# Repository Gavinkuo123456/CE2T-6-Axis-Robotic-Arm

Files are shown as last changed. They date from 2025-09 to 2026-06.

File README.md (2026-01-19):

# Cost-Effective 6 DOF robotic arm

A budget friendly 6-degree-of-freedom homemade robotic arm offering both precision and a strong load capacity for its price range.

Robot Arm CAD
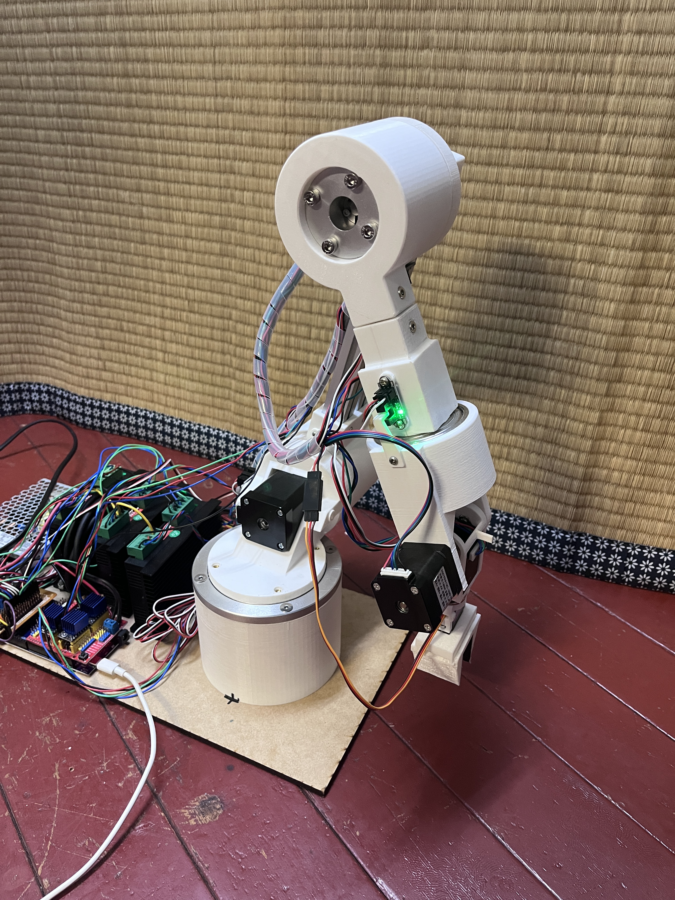
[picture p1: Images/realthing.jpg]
Robot Arm real


## 🤖 Overview

This project features a fully functional 6-DOF robotic arm that combines:
- **3D printed mechanical components** for easy production and construction
- **Stepper motor actuation** for precise positioning
- **Powerfull motor controller** for driving high-torque motors with precise control
- **Arduino-based control system** for accessibility and expandability
- **Open-loop control** for simplicity, budget-friendly and easy maintenance

## ✨ Features

- **6 Degrees of Freedom**: Full spatial movement capability
- **Stepper Motor Control**: Precise angular positioning
- **3D Printable Design**: Accessible manufacturing with standard FDM printers
- **Arduino Compatible**: Easy programming and customization
- **Open Source**: Complete design files and code available
- **standard hardware**: Easy assembly and easy to find online

## 📋 Specifications

| Parameter | Value |
|---|---|
| Degrees of Freedom | 6 |
| Motor Type | Stepper Motors |
| Control System | Arduino-based |
| Control Method | Open-loop |
| Construction | 3D Printed frame + Standard Components |
| Workspace | 500mm radius |
| Payload Capacity | ~500g |
| Repeatability | ✅ |

## 🛠️ Hardware Requirements

### Electronics
- **Arduino Board** Arduino Due
- **Stepper Motor Drivers** TMC2209 × 3 , DM542 x 3
- **Stepper Motors**
   - **Joint 1** NEMA23L56
   - **Joint 2** NEMA17L60 with 1:50 planetary gearbox
   - **Joint 3** NEMA17L48 with 1:27 planetary gearbox
   - **Joint 4** NEMA11L33 with 1:20 planetary gearbox
   - **Joint 5** NEMA14L20
   - **Joint 6** NEMA11L33
- **Power Supply** 24V 100W
- **Limit Switches** optical endstop x 6
- **Pin Header** and **General-Purpose Printed Circuit Board**(for the only custom expansion board)

### Frame
- **3D Printed Parts** (see `/3D-model` folder)

### Mechanical Components
- **Bearings** 
   - 6009 x 2
   - 6007 x1
- **Screws and Fasteners** M3, M4, M5 bolts and nuts

### Tools Required
- 3D Printer (FDM, 200×200×200mm minimum build volume)
- Screwdrivers
- Allen keys/Hex keys
- Wire strippers
- Multimeter
- Laser cutter(optional, You can use drill and hand saw)

## 🔧 Assembly Instructions

Detailed assembly instructions with images available in `/Docs/Assembly instructions.docx`

## 💻 Software Setup

### Prerequisites
- Arduino IDE (latest version)
- Required Libraries:
  - `AccelStepper`
  - `MultiStepper`
  - `math`
  - `Servo` (if using servo gripper)

## 🎮 Usage

### Basic Control
The robot arm can be controlled through:
- **Serial Commands**: Send position commands via serial monitor
- **I2C**: Send position from other device or microcontroller

### Command Examples
```
// Move to joint positions (degrees)
jm 45 30 -20 0 45 90

// Move to Cartesian position (first three in mm,last three in rad)
IK 200 150 100 0 90 0

// Home all joints
zro

// Control gripper
clm 95

```

## 📊 Kinematics

The robot arm uses standard Denavit-Hartenberg parameters for kinematic calculations. Forward and inverse kinematics algorithms are implemented for position control.

### Joint Configuration
- **Joint 1**: Base rotation (±90°)
- **Joint 2**: Shoulder pitch (±90°)
- **Joint 3**: Elbow pitch (±160°)
- **Joint 4**: Wrist roll (±180°)
- **Joint 5**: Wrist pitch (±90°)
- **Joint 6**: Wrist yaw (±180°)

## 🚀 Future Enhancements

- [ ] Closed-loop control with encoders
- [ ] Vision system integration
- [ ] ROS compatibility
- [ ] Mobile app(Browser) control
- [ ] Advanced path planning
- [ ] Machine learning integration
- [ ] Multi-arm coordination

## 🤝 Contributing

Contributions are welcome! Please feel free to submit pull requests, report bugs, or suggest improvements.

## 📝 License

This project is licensed under the MIT License - see the [LICENSE](LICENSE) file for details.

## 🙏 Acknowledgments

- Arduino community for libraries and support
- 3D printing community for design inspiration
- Robotics researchers for kinematic algorithms
- Open-source contributors

**⭐ Star this repository if you find it helpful!**

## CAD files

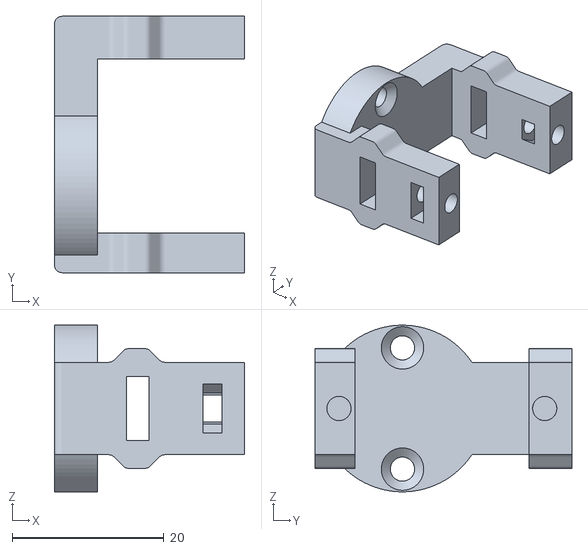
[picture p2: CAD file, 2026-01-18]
3D-model/3D print and Laser cut file/sg90 claw v2 holder.stl
25.1 x 33.8 x 22.0

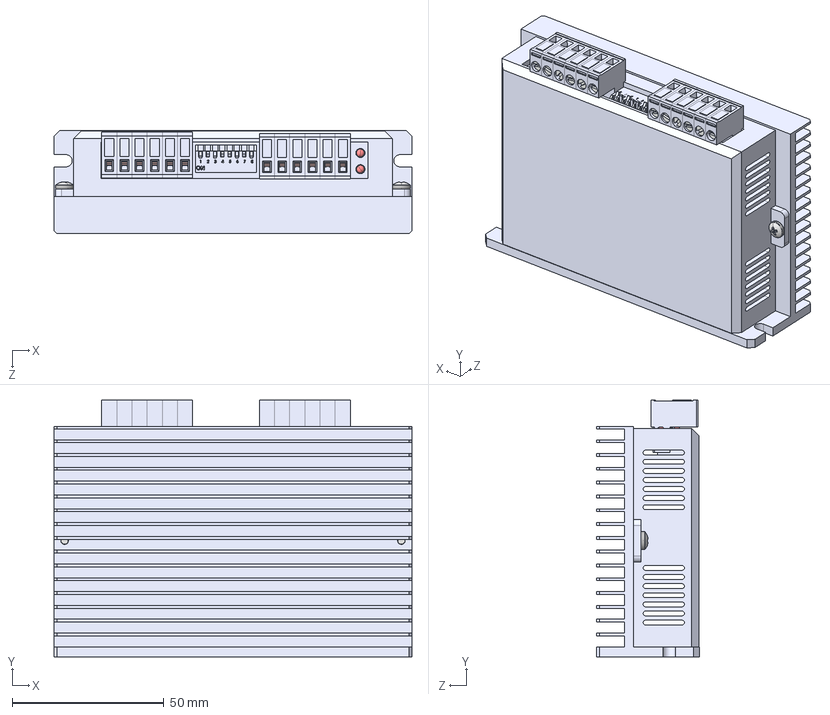
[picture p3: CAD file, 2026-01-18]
3D-model/robot armT 2(CAD file)/DM542.STEP
118.0 x 84.6 x 34.0 mm
散熱片
外殼
Pan Head M3x5_96741A118 x 2
端子(1P) x 12
ｩTｩwﾁｳｵｷ x 12
緊迫 x 12
LED x 2
DIP Switch
Switch x 8

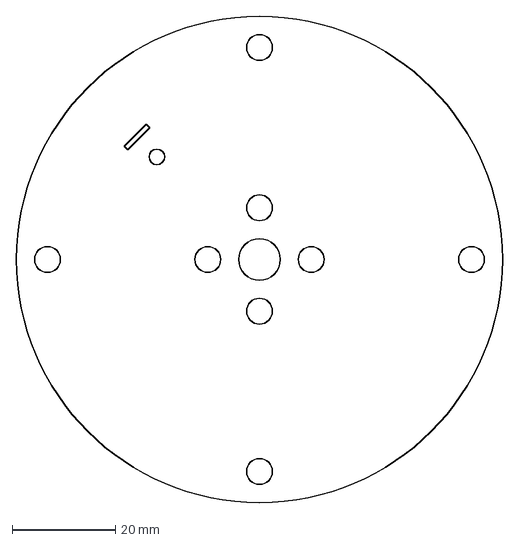
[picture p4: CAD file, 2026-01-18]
3D-model/3D print and Laser cut file/j1 moving plate laser cut.dxf
94.0 x 94.0 mm

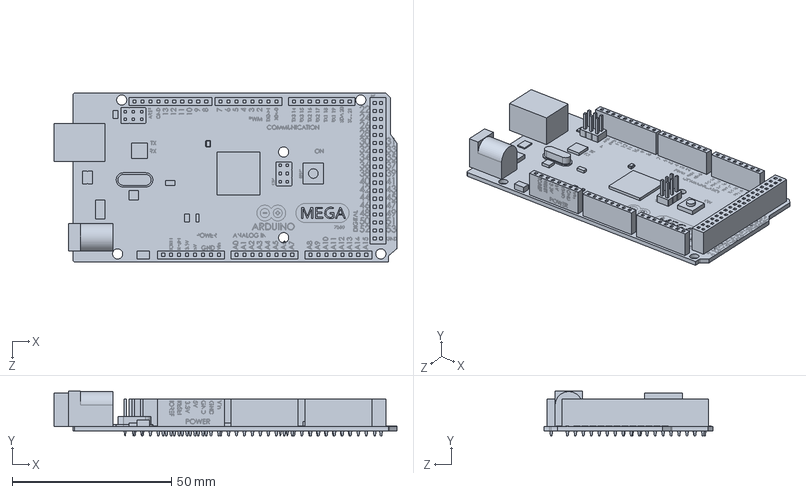
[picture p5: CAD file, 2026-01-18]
3D-model/robot armT 2(CAD file)/ArduinoMega2560.SLDPRT
107.6 x 14.0 x 53.0 mm

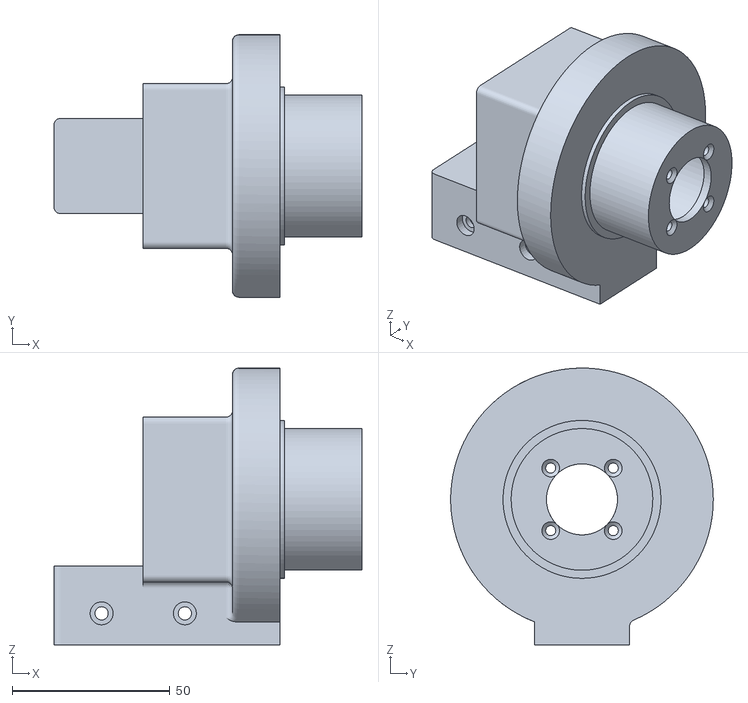
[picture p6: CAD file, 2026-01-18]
3D-model/3D print and Laser cut file/j3 motor mount.stl
97.5 x 83.1 x 87.6

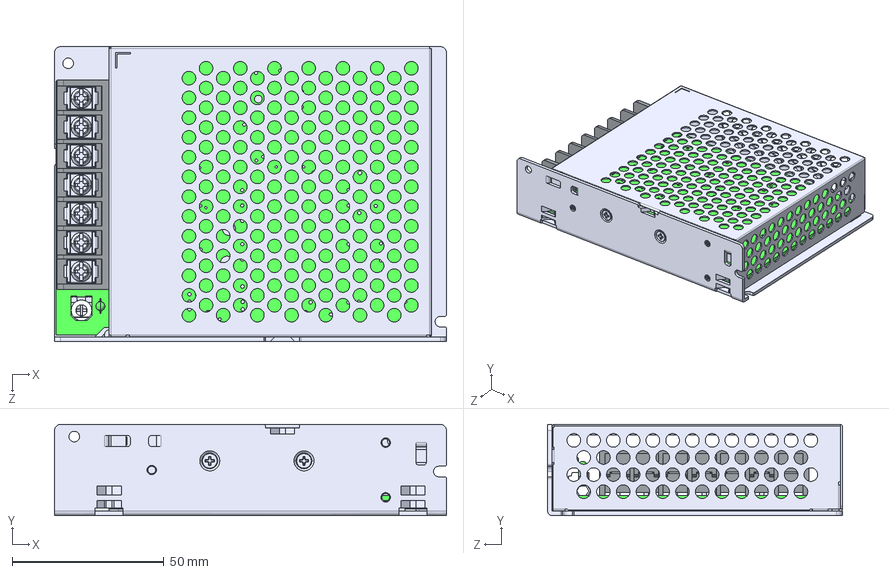
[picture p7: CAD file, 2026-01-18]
3D-model/robot armT 2(CAD file)/VTX-212-100-0xx.STEP
129.0 x 30.0 x 97.0 mm
CHASSIS_40
LUOZHU_2
COVER_29
PRT0028_2
PRT0052_2 x 2
PRT0053_3 x 2
PRT0054_AF0_2
PRT0054_AF1_2
PRT0054_AF2_2
PRT0054_AF3_2
PRT0054_AF4_2
PRT0054_AF5_2
PRT0054_AF6_2
PRT0054_AF7_2
PRT0054_AF8_2
PRT0054_AF9_2
PRT0054_AF10_2
PRT0054_AF11_2
PRT0054_AF12_2
PRT0054_AF13_2
PRT0054_AF14_2
PRT0054_AF15_2
PRT0055_2 x 32
PRT0056_2 x 32
PRT0061_AF0_2
KM3X10_3 x 2
KM3X5_2
PRT0054_2 x 16
PRT0061_2

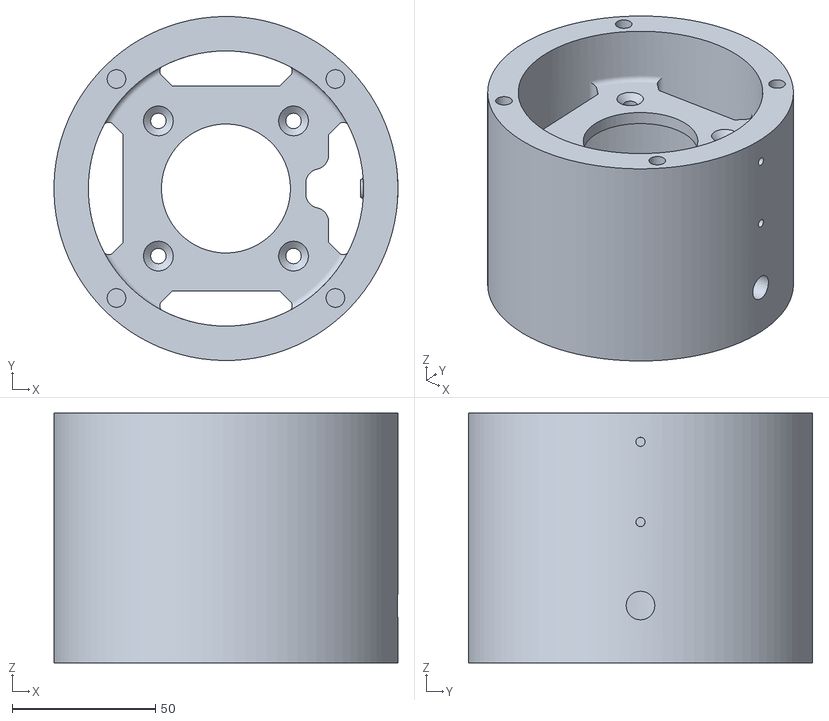
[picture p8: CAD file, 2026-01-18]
3D-model/3D print and Laser cut file/j1 57 mount.stl
120.0 x 120.0 x 87.1

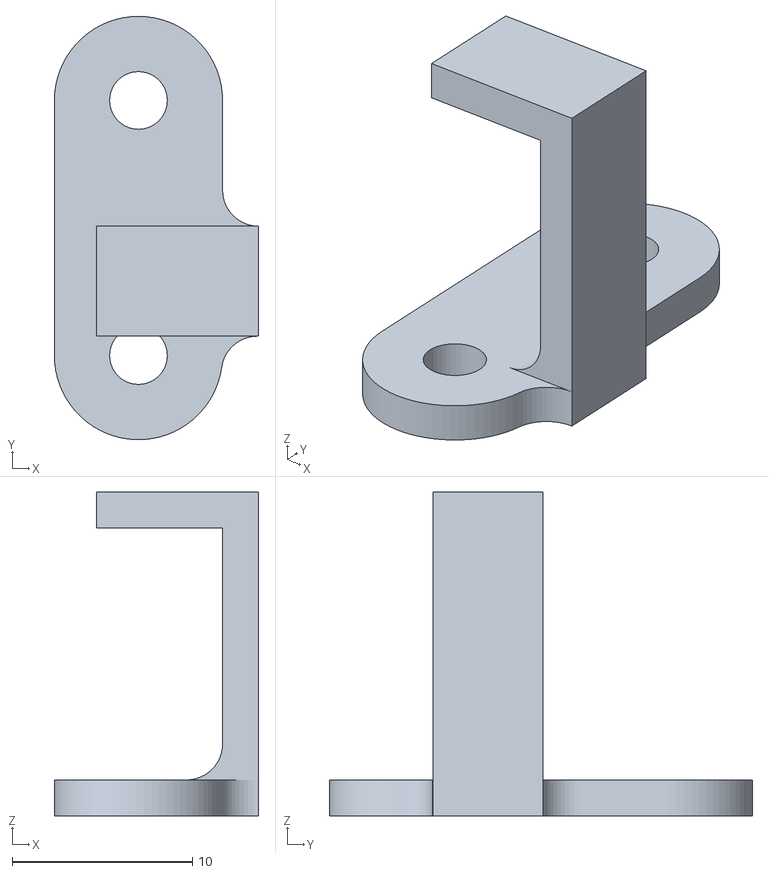
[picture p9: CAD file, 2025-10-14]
3D-model/3D print and Laser cut file/j2 endstop blocker.stl
11.3 x 23.5 x 18.0

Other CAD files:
3D-model/robot armT 2(CAD file)/AS 1427 - M3 x 6(5) II.ipt
3D-model/robot armT 2(CAD file)/AS 1474 - M3(1).ipt
3D-model/robot armT 2(CAD file)/AS 1474 - M4(1).ipt
3D-model/robot armT 2(CAD file)/ArduinoMega2560/ArduinoMega2560/ArduinoMega2560.ipt
3D-model/robot armT 2(CAD file)/CNS 2862 B2116 - 6007 - 35 x 62 x 14.ipt
3D-model/robot armT 2(CAD file)/CNS 4557 - M4 x 0.7 x 10.ipt
3D-model/robot armT 2(CAD file)/CNS 4558 - M3 x 0.5 x 10.ipt
3D-model/robot armT 2(CAD file)/DM542/DM542/DM542.ipt
3D-model/robot armT 2(CAD file)/M3 heat set insert.ipt
3D-model/robot armT 2(CAD file)/M3 heat set inserts.ipt
3D-model/robot armT 2(CAD file)/M5 heat set inserts.ipt
3D-model/robot armT 2(CAD file)/OldVersions/CNS 2862 B2116 - 6007 - 35 x 62 x 14.0001.ipt
3D-model/robot armT 2(CAD file)/OldVersions/base plate.0005.ipt
3D-model/robot armT 2(CAD file)/OldVersions/j1 57 mount.0015.ipt
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

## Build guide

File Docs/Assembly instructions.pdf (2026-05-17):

## Laser cut Plate preparation

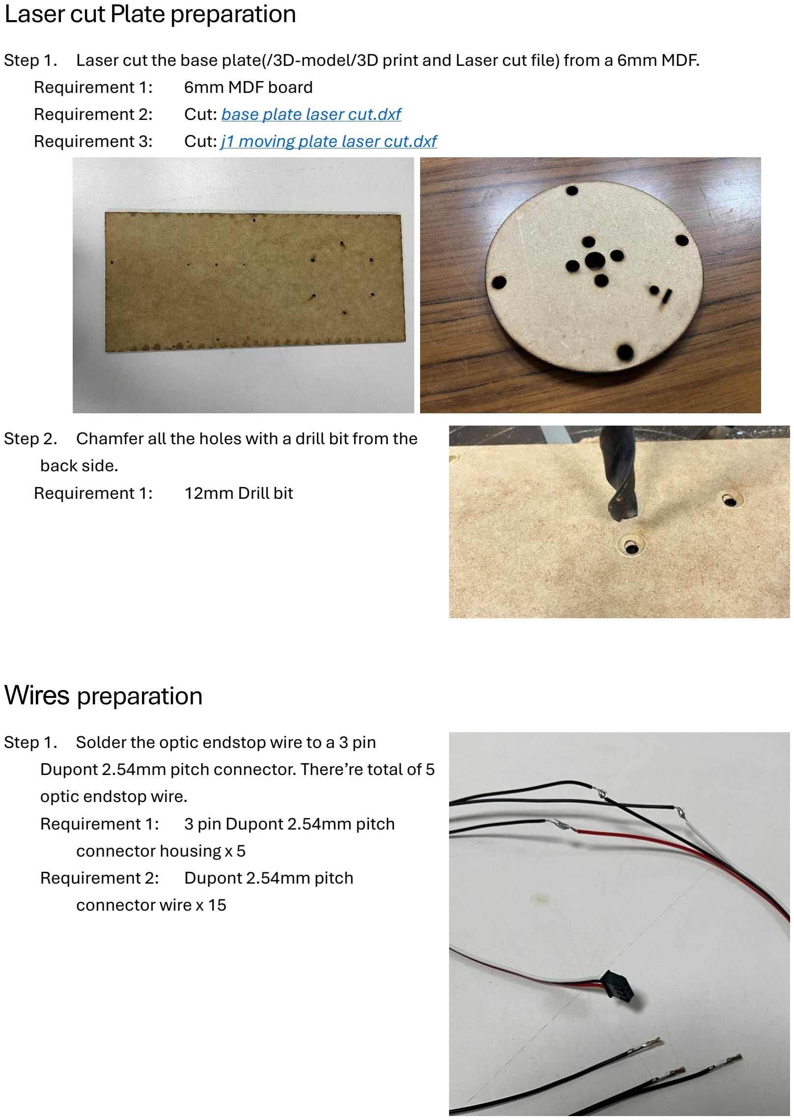
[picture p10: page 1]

Step 1. Laser cut the base plate(/3D-model/3D print and Laser cut file) from a 6mm MDF.
Requirement 1: | 6mm MDF board
Requirement 2: | Cut: base plate laser cut.dxf (https://github.com/Gavinkuo123456/CE2T-6-Axis-Robotic-Arm/blob/main/3D-model/3D%20print%20and%20Laser%20cut%20file/base%20plate%20laser%20cut.dxf)
Requirement 3: | Cut: j1 moving plate laser cut.dxf (https://github.com/Gavinkuo123456/CE2T-6-Axis-Robotic-Arm/blob/main/3D-model/3D%20print%20and%20Laser%20cut%20file/j1%20moving%20plate%20laser%20cut.dxf)
Step 2. Chamfer all the holes with a drill bit from the back side.
Requirement 1: 12mm Drill bit

## Wires preparation

Step 1. Solder the optic endstop wire to a 3 pin Dupont 2.54mm pitch connector. There’re total of 5 optic endstop wire.
Requirement 1: 3 pin Dupont 2.54mm pitch connector housing x 5
Requirement 2: Dupont 2.54mm pitch connector wire x 15

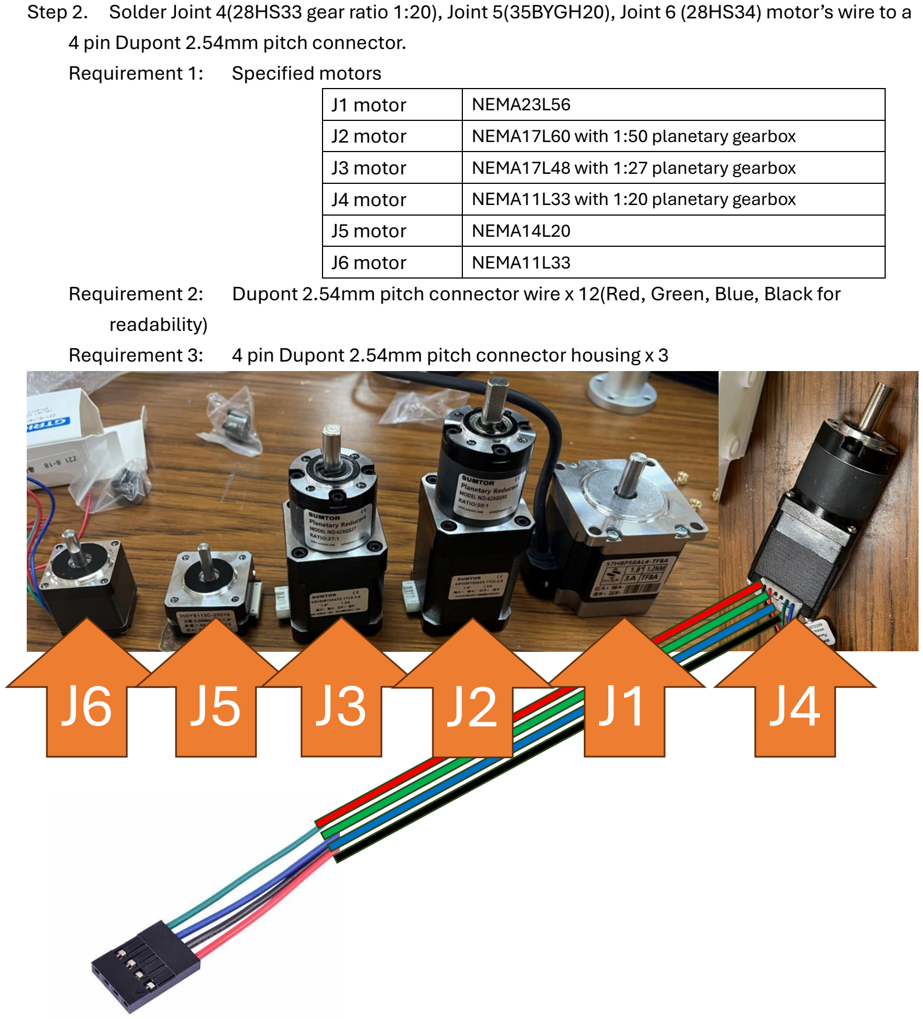
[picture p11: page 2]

Step 2. Solder Joint 4(28HS33 gear ratio 1:20), Joint 5(35BYGH20), Joint 6 (28HS34) motor’s wire to a 4 pin Dupont 2.54mm pitch connector.
Requirement 1: Specified motors
J1 motor | NEMA23L56
J2 motor | NEMA17L60 with 1:50 planetary gearbox
J3 motor | NEMA17L48 with 1:27 planetary gearbox
J4 motor | NEMA11L33 with 1:20 planetary gearbox
J5 motor | NEMA14L20
J6 motor | NEMA11L33
Requirement 2: Dupont 2.54mm pitch connector wire x 12(Red, Green, Blue, Black for readability)
Requirement 3: 4 pin Dupont 2.54mm pitch connector housing x 3
J6 J5 J3 J2 | J1 | J4

## Joint 1 assembly

3D printed parts
1. j1 57 mount.stl (https://github.com/Gavinkuo123456/CE2T-6-Axis-Robotic-Arm/blob/main/3D-model/3D%20print%20and%20Laser%20cut%20file/j1%2057%20mount.stl)
2. j1 endstop block v2.stl (https://github.com/Gavinkuo123456/CE2T-6-Axis-Robotic-Arm/blob/main/3D-model/3D%20print%20and%20Laser%20cut%20file/j1%20endstop%20block%20v2.stl)
Step 1. Tap M5 threads into 8mm flange coupling Requirement 1: 8mm flange coupling Requirement 2: M5 Taps

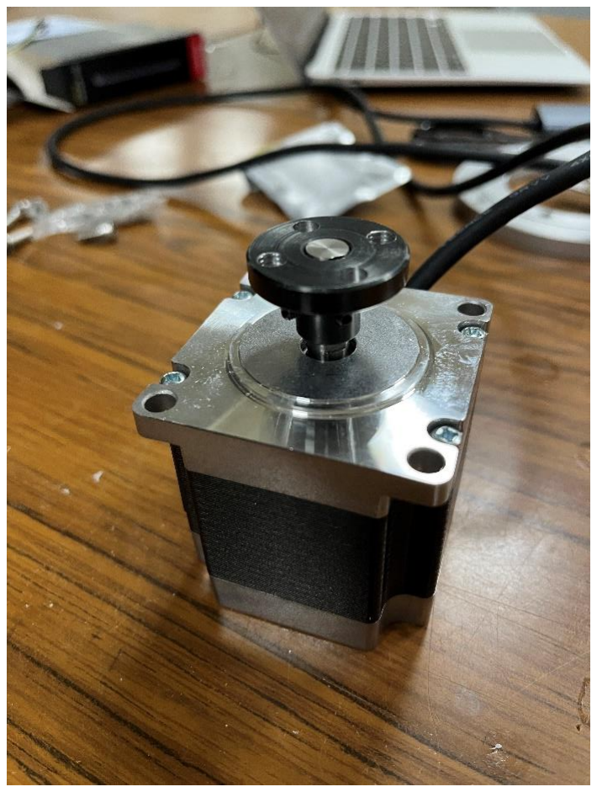
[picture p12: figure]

Step 2. Install the Coupling on to the shaft of the NEMA 23 motor.
Requirement 1: NEMA23 x 56mm Requirement 2: Tapped 8mm coupling

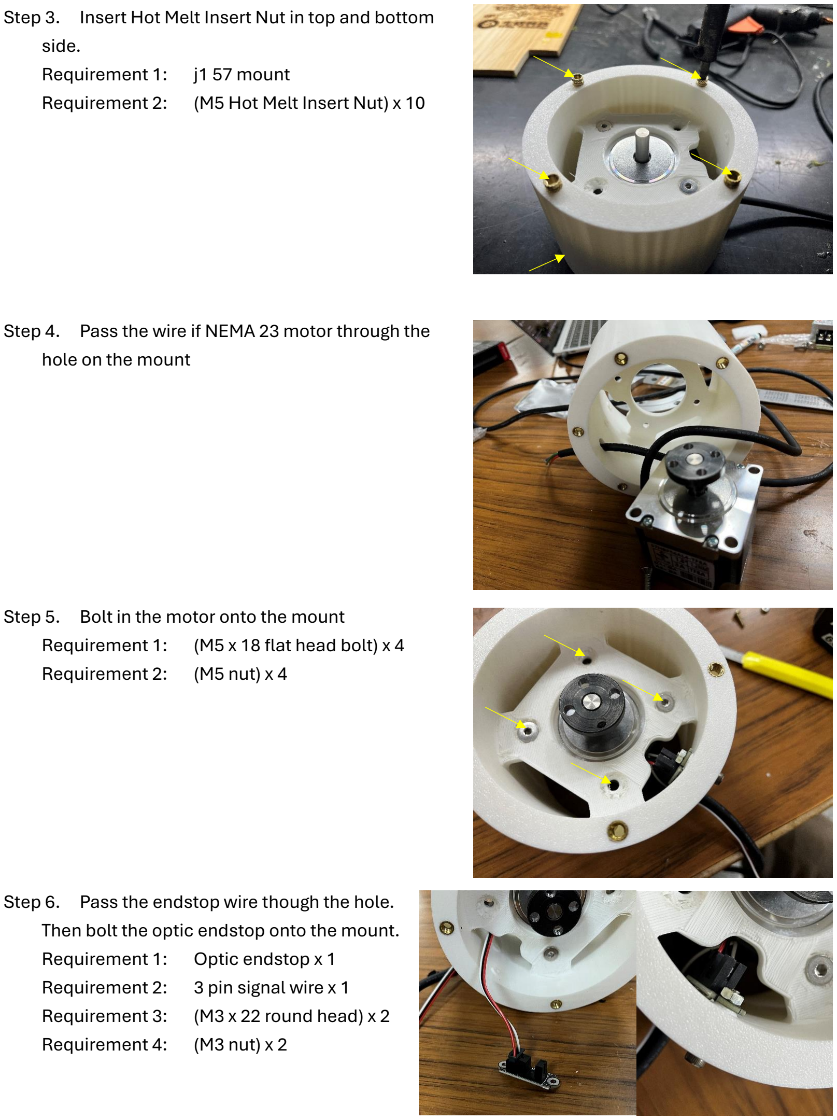
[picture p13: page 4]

Step 3. Insert Hot Melt Insert Nut in top and bottom side.
Requirement 1: j1 57 mount
Requirement 2: (M5 Hot Melt Insert Nut) x 10
Step 4. Pass the wire if NEMA 23 motor through the hole on the mount
Step 5. Bolt in the motor onto the mount Requirement 1: (M5 x 18 flat head bolt) x 4 Requirement 2: (M5 nut) x 4
Step 6. Pass the endstop wire though the hole. Then bolt the optic endstop onto the mount. Requirement 1: Optic endstop x 1 Requirement 2: 3 pin signal wire x 1 Requirement 3: (M3 x 22 round head) x 2 Requirement 4: (M3 nut) x 2

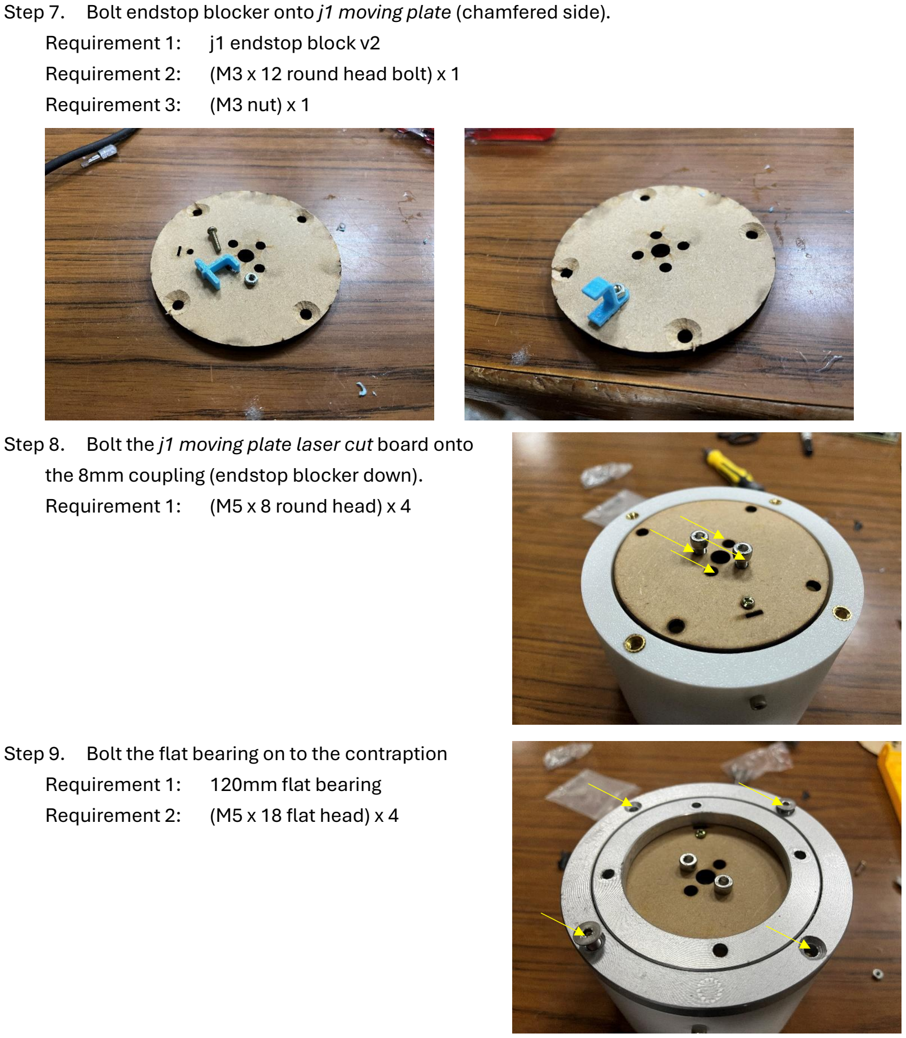
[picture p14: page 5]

Step 7. Bolt endstop blocker onto j1 moving plate (chamfered side). Requirement 1: j1 endstop block v2
Requirement 2: (M3 x 12 round head bolt) x 1
Requirement 3: (M3 nut) x 1
Step 8. Bolt the j1 moving plate laser cut board onto the 8mm coupling (endstop blocker down). Requirement 1: (M5 x 8 round head) x 4
Step 9. Bolt the flat bearing on to the contraption Requirement 1: 120mm flat bearing Requirement 2: (M5 x 18 flat head) x 4

Joint 2 assembly

Step 1. prepare the necessary parts

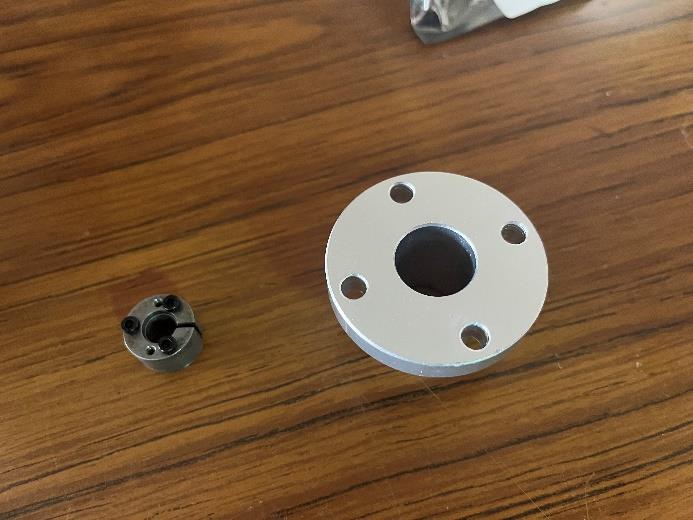
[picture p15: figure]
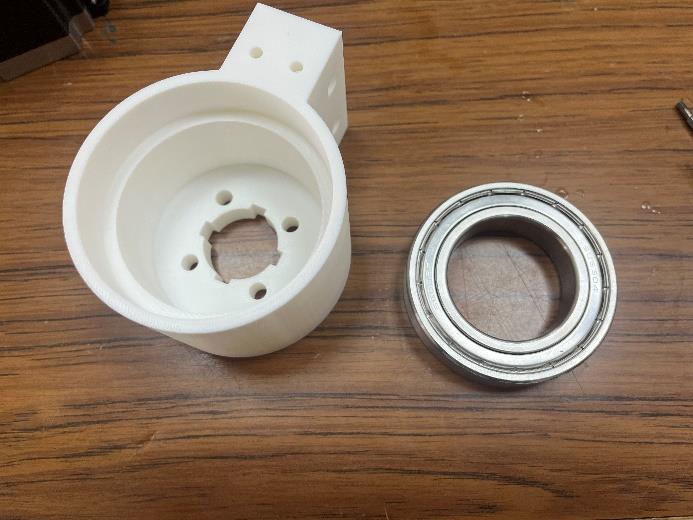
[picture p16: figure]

Step 2. Install Insert Nut on j2 42 motor mount.stl (https://github.com/Gavinkuo123456/CE2T-6-Axis-Robotic-Arm/blob/main/3D-model/3D%20print%20and%20Laser%20cut%20file/j2%2042%20motor%20mount.stl) and j2 moving part option2.stl (https://github.com/Gavinkuo123456/CE2T-6-Axis-Robotic-Arm/blob/main/3D-model/3D%20print%20and%20Laser%20cut%20file/j2%20moving%20part%20option2.stl)
Requirement 1: | (heat M5 Hot Melt Insert Nut) x 8
Requirement 2: | (heat M3 Hot Melt Insert Nut) x 4

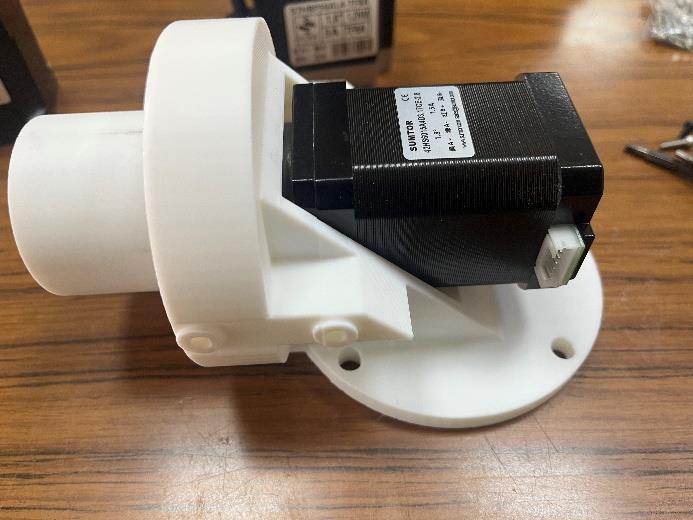
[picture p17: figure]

Step 3. Install J2 motor in to the mount, use 4 screws to hold it in place
Requirement 1: | J2 motor
Requirement 2: | (M3 x 6 flathead) x 4
Step 4. Assemble axle locking assembly, tighten the allen screws by the side of the flange Requirement 1: Expansion Bushing (Z21-ID 8 * OD 18)
Requirement 2: Flange (ID18)

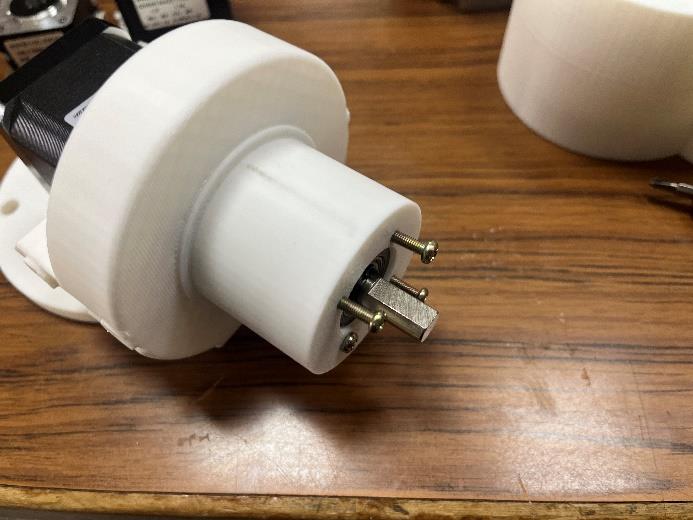
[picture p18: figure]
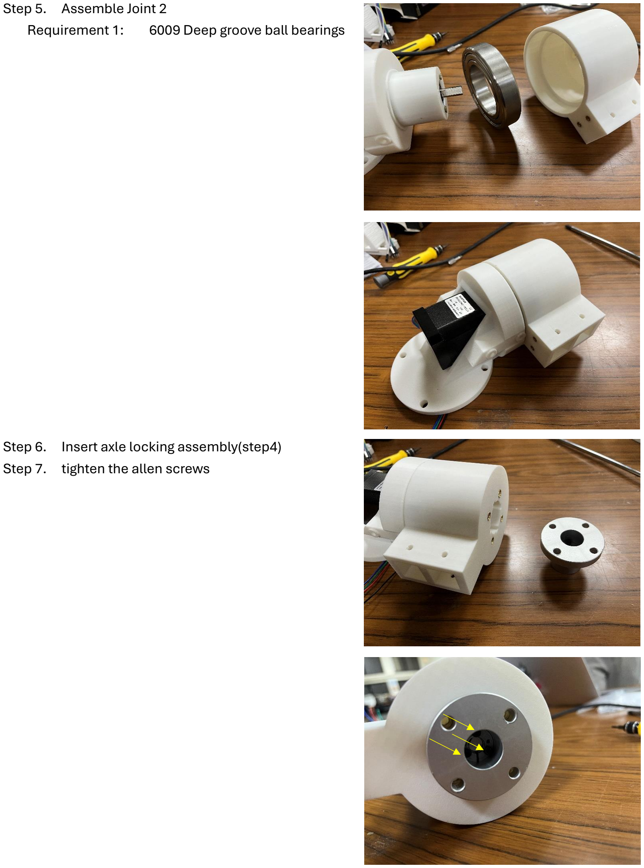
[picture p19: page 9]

Step 5. Assemble Joint 2
Requirement 1: 6009 Deep groove ball bearings
Step 6. Insert axle locking assembly(step4)
Step 7. tighten the allen screws

Step 8. Fasten connecting bolts Requirement 1: (M5 x 16) x 4

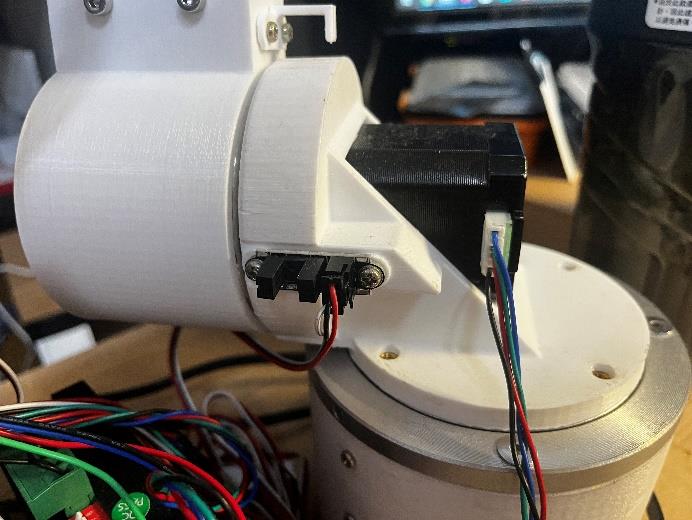
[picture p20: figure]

Step 9. Install endstop, make sure it is facing the right direction
Requirement 1: | Optical endstop
Requirement 2: | (M3x6) x 2
Step 10. Install endstop blocker
Requirement 1: | j2 endstop blocker.stl (https://github.com/Gavinkuo123456/CE2T-6-Axis-Robotic-Arm/blob/main/3D-model/3D%20print%20and%20Laser%20cut%20file/j2%20endstop%20blocker.stl)
Requirement 2: | (M3x6) x 2

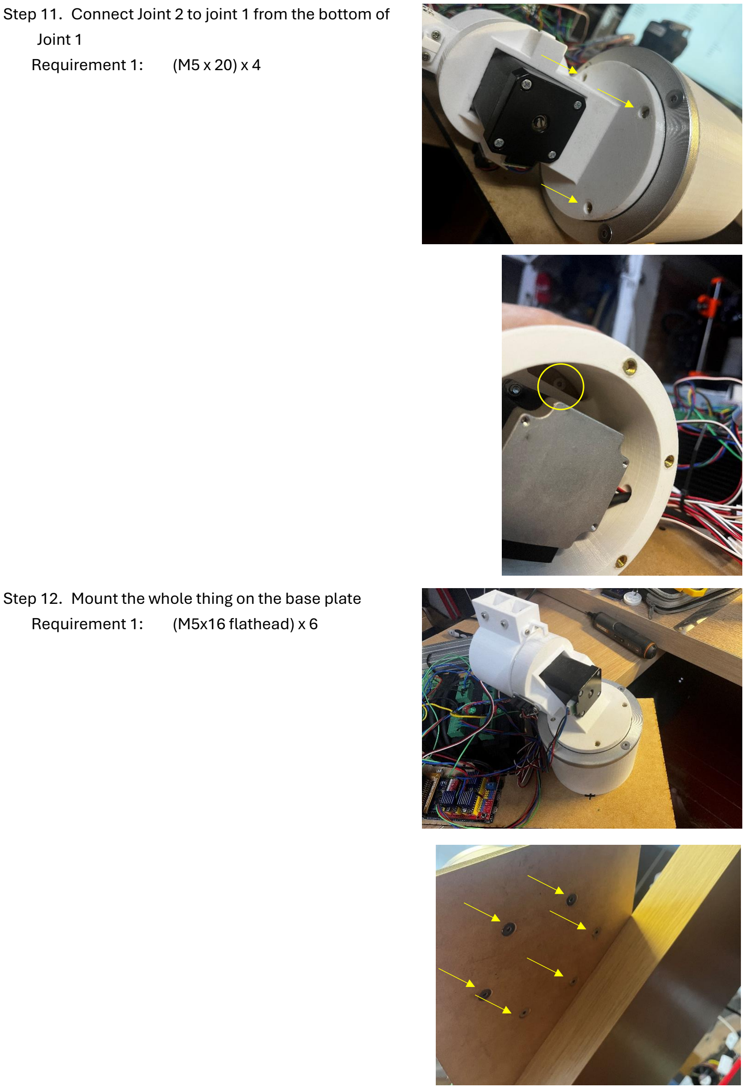
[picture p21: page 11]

Step 11. Connect Joint 2 to joint 1 from the bottom of Joint 1
Requirement 1: (M5 x 20) x 4
Step 12. Mount the whole thing on the base plate Requirement 1: (M5x16 flathead) x 6

Joint 3 assembly

Step 1. Prepare the necessary parts

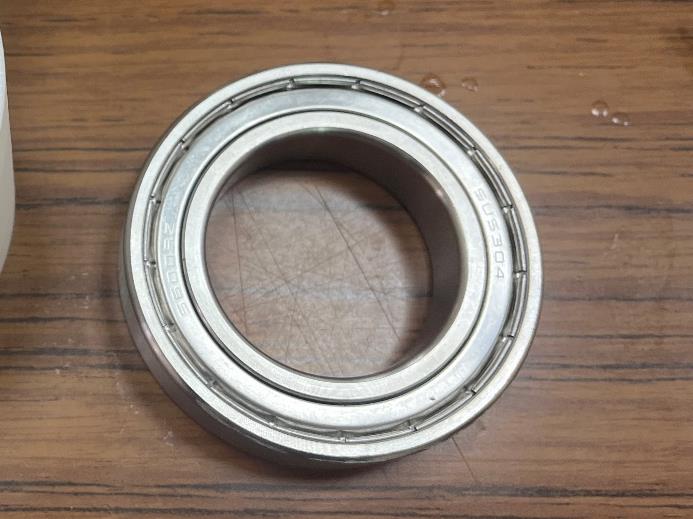
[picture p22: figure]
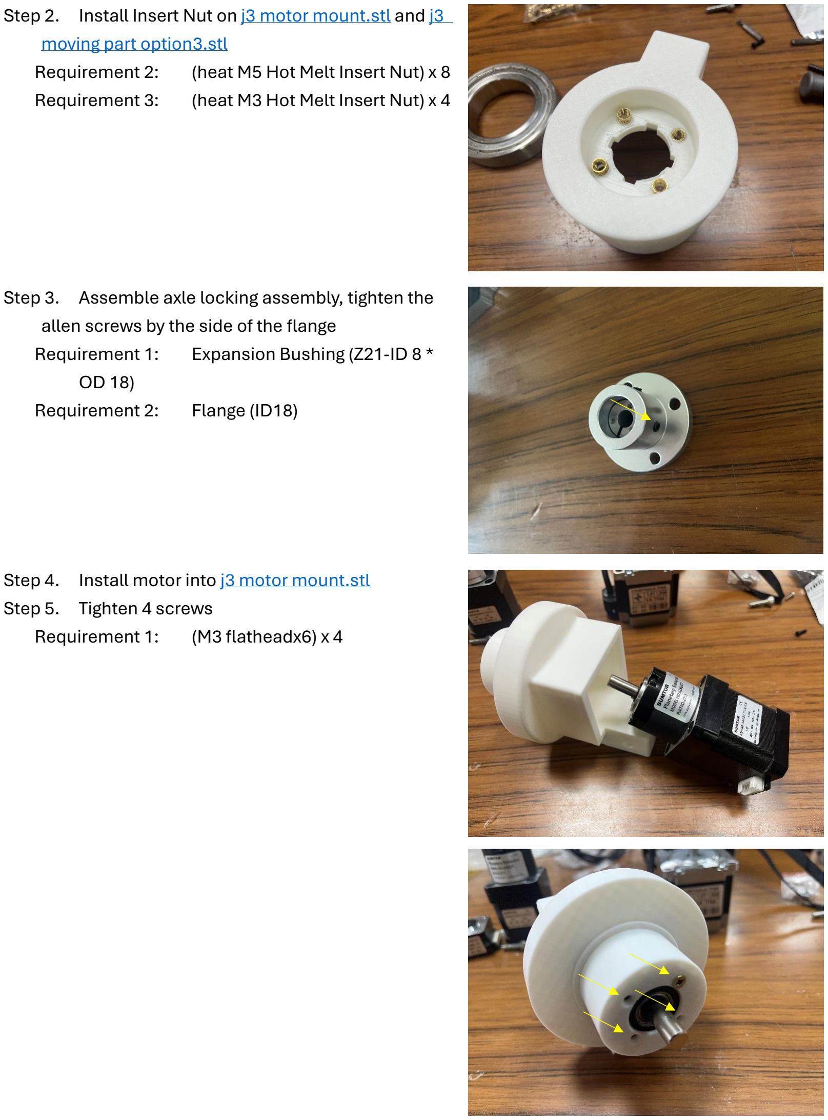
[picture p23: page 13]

Step 2. Install Insert Nut on j3 motor mount.stl (https://github.com/Gavinkuo123456/CE2T-6-Axis-Robotic-Arm/blob/main/3D-model/3D%20print%20and%20Laser%20cut%20file/j3%20motor%20mount.stl) and j3 moving part option3.stl (https://github.com/Gavinkuo123456/CE2T-6-Axis-Robotic-Arm/blob/main/3D-model/3D%20print%20and%20Laser%20cut%20file/j3%20moving%20part%20option3.stl)
Requirement 2: | (heat M5 Hot Melt Insert Nut) x 8
Requirement 3: | (heat M3 Hot Melt Insert Nut) x 4
Step 3. Assemble axle locking assembly, tighten the allen screws by the side of the flange Requirement 1: Expansion Bushing (Z21-ID 8 * OD 18)
Requirement 2: Flange (ID18)
Step 4. Install motor into j3 motor mount.stl (https://github.com/Gavinkuo123456/CE2T-6-Axis-Robotic-Arm/blob/main/3D-model/3D%20print%20and%20Laser%20cut%20file/j3%20motor%20mount.stl)
Step 5. Tighten 4 screws
Requirement 1: (M3 flatheadx6) x 4

Step 6. Install axle locking assembly into j3 moving part option3(step 2) and tighten 4 bolts Requirement 1: (M5 x 16) x 4

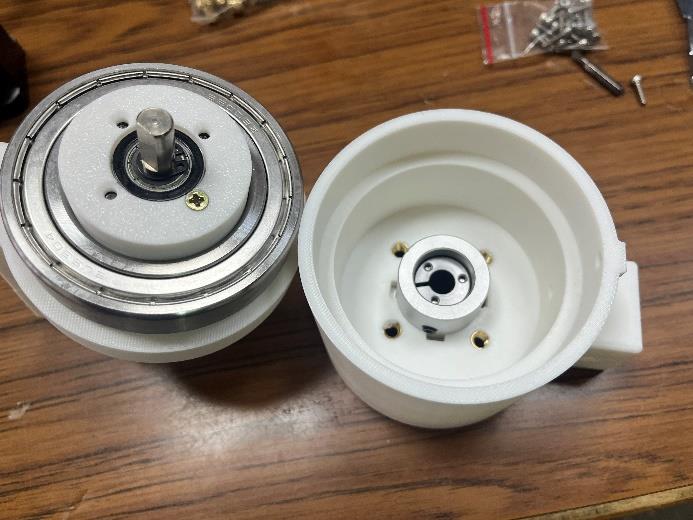
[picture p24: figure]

Step 7. Assemble joint 3

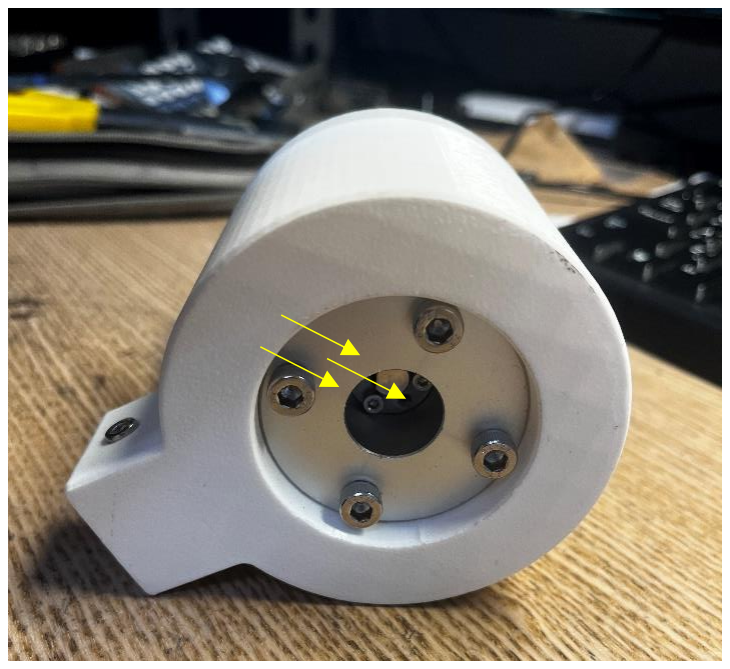
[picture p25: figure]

Step 8. Tighten the allen screws

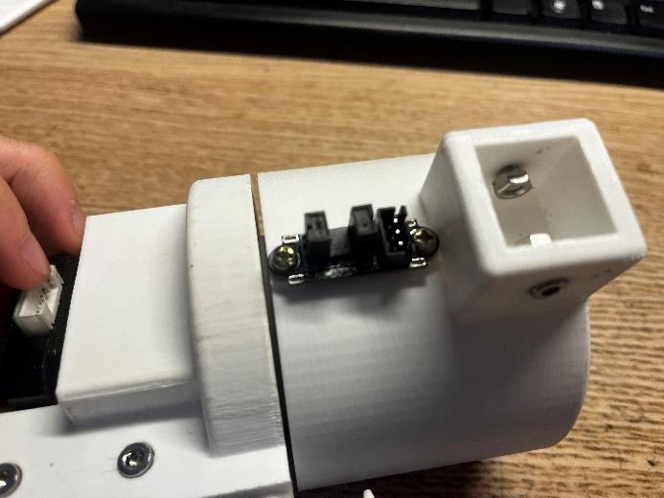
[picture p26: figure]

Step 9. Install endstop, make sure it is facing the right direction
Requirement 1: | Optical endstop
Requirement 2: | (M3x6) x 2
Step 10. Install endstop blocker
Requirement 1: | j3 endstop blocker.stl (https://github.com/Gavinkuo123456/CE2T-6-Axis-Robotic-Arm/blob/main/3D-model/3D%20print%20and%20Laser%20cut%20file/j3%20endstop%20blocker.stl)
Requirement 2: | (M3x6) x 2

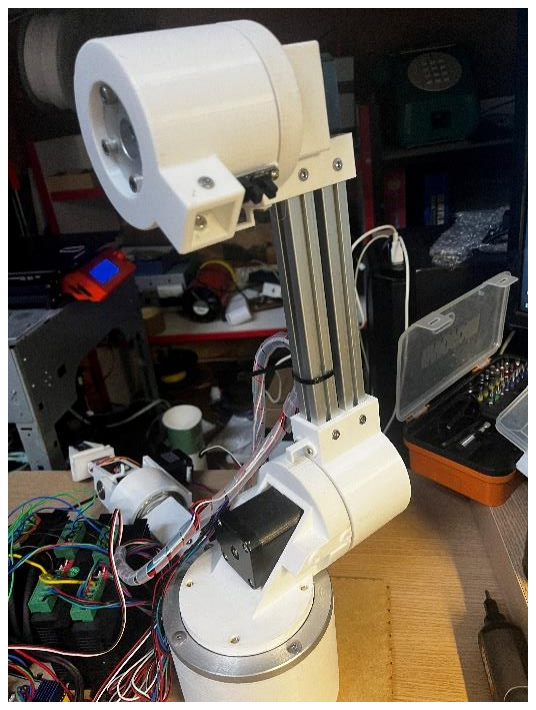
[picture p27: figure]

Step 11. Connect Joint 3 to the base part, blot down the whole thing with M4 bolts and buts
Requirement 1: | 2020aluminum extrusion 180mm
Requirement 2: | (M4x8) x 8
Requirement 3: | M4 nuts x 8
Step 12. 50% of the arm is complete

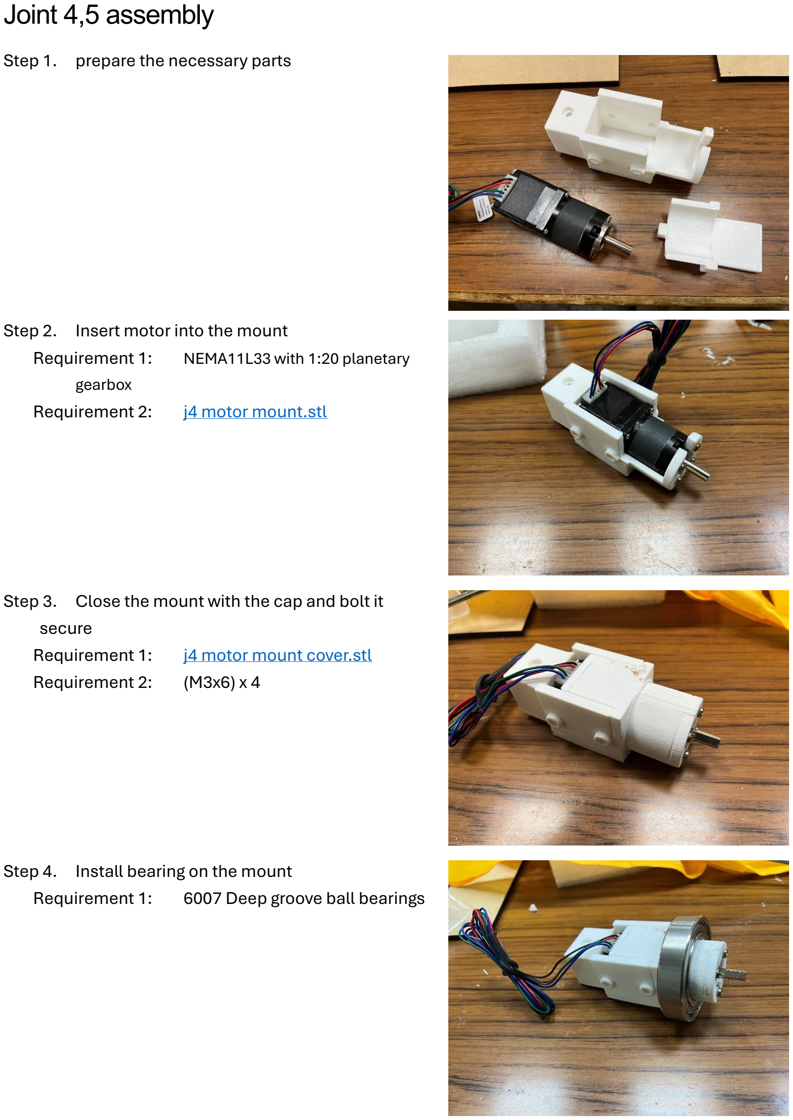
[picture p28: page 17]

Joint 4,5 assembly

Step 1. prepare the necessary parts
Step 2. Insert motor into the mount
Requirement 1: NEMA11L33 with 1:20 planetary gearbox
Requirement 2: j4 motor mount.stl (https://github.com/Gavinkuo123456/CE2T-6-Axis-Robotic-Arm/blob/main/3D-model/3D%20print%20and%20Laser%20cut%20file/j4%20motor%20mount.stl)
Step 3. Close the mount with the cap and bolt it secure
Requirement 1: | j4 motor mount cover.stl (https://github.com/Gavinkuo123456/CE2T-6-Axis-Robotic-Arm/blob/main/3D-model/3D%20print%20and%20Laser%20cut%20file/j4%20motor%20mount%20cover.stl)
Requirement 2: | (M3x6) x 4
Step 4. Install bearing on the mount
Requirement 1: 6007 Deep groove ball bearings

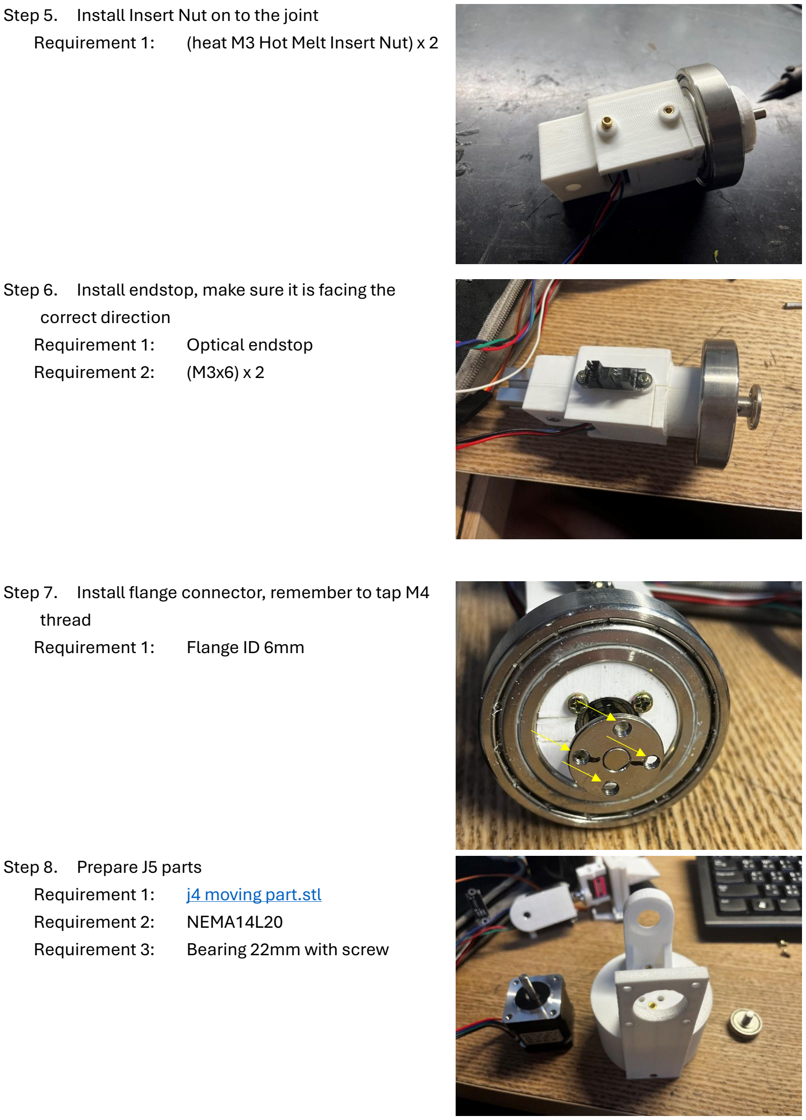
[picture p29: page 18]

Step 5. Install Insert Nut on to the joint
Requirement 1: (heat M3 Hot Melt Insert Nut) x 2
Step 6. Install endstop, make sure it is facing the correct direction
Requirement 1: | Optical endstop
Requirement 2: | (M3x6) x 2
Step 7. Install flange connector, remember to tap M4 thread
Requirement 1: Flange ID 6mm
Step 8. Prepare J5 parts
Requirement 1: | j4 moving part.stl (https://github.com/Gavinkuo123456/CE2T-6-Axis-Robotic-Arm/blob/main/3D-model/3D%20print%20and%20Laser%20cut%20file/j4%20moving%20part.stl)
Requirement 2: | NEMA14L20
Requirement 3: | Bearing 22mm with screw

Step 9. Install Insert Nut
Requirement 1: (heat M3 Hot Melt Insert Nut) x 3
Step 10. Assemble joint 4 and joint 5
Step 11. Bolt down joint 5 to joint 4 motor Requirement 1: (M5x10) x 4

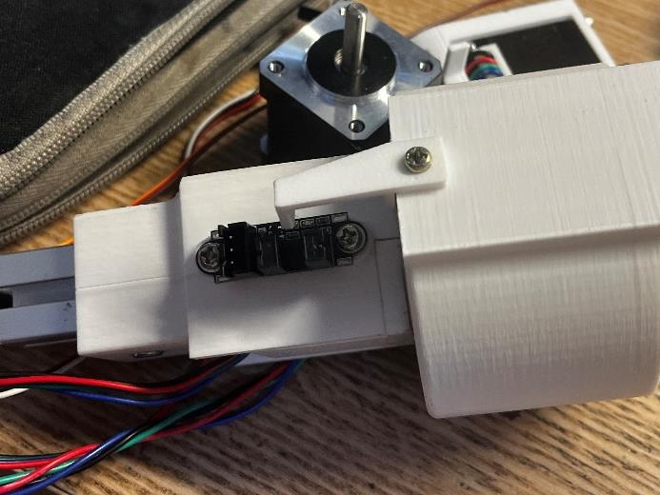
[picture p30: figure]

Step 12. Install endstop blocker
Requirement 1: | j4 endstop blocker.stl (https://github.com/Gavinkuo123456/CE2T-6-Axis-Robotic-Arm/blob/main/3D-model/3D%20print%20and%20Laser%20cut%20file/j4%20endstop%20blocker.stl)
Requirement 2: | M3x6

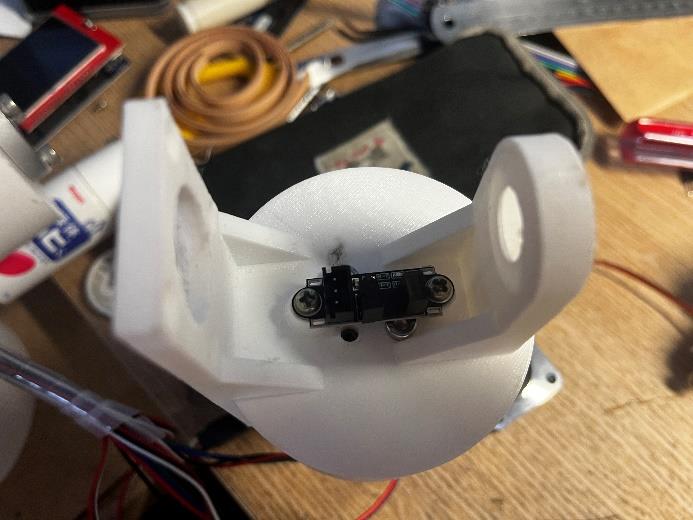
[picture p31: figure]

Step 13. Install endstop
Requirement 1: | Optical endstop
Requirement 2: | (M3x6) x 2

We need to jump to Joint 6 assembly for now Joint 6 assembly

Step 1. Prepare the parts

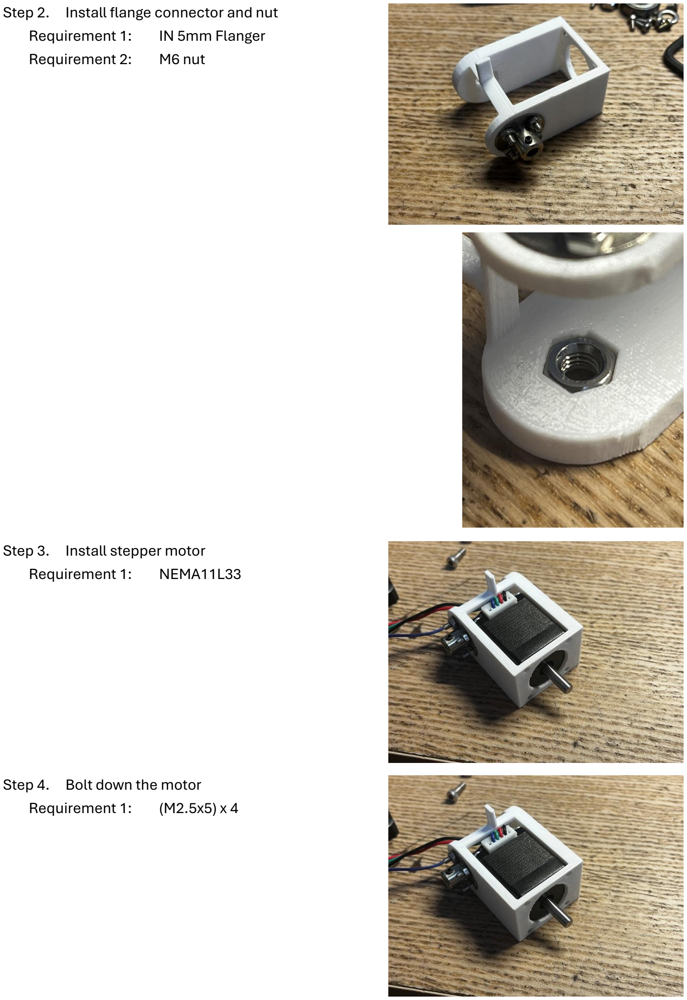
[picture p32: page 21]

Step 2. Install flange connector and nut
Requirement 1: | IN 5mm Flanger
Requirement 2: | M6 nut
Step 3. Install stepper motor Requirement 1: NEMA11L33
Step 4. Bolt down the motor Requirement 1: (M2.5x5) x 4

Step 5.
Step 6. Connect joint 6 to Joint 4,5 part(bearing side)
Step 14. Connect Joint 6 to Joint 5 motor axle and bolt down the allen screw
Step 15. Bolt down joint 5 motor Requirement 1: (M3flatheadx5) x 4

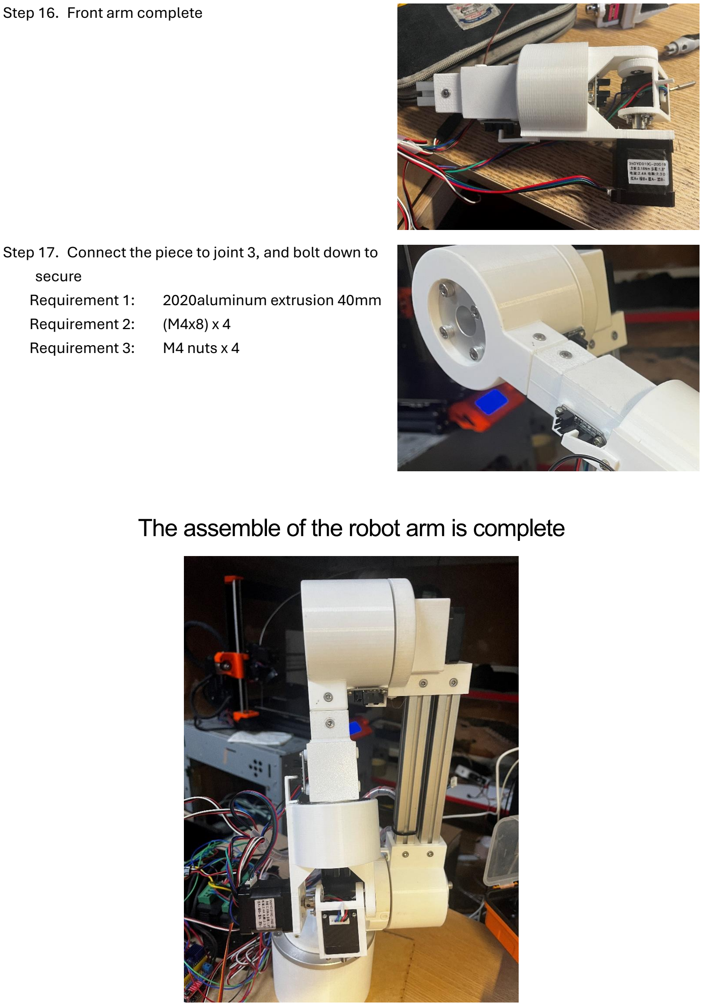
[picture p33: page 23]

Step 16. Front arm complete
Step 17. Connect the piece to joint 3, and bolt down to secure
Requirement 1: | 2020aluminum extrusion 40mm
Requirement 2: | (M4x8) x 4
Requirement 3: | M4 nuts x 4

The assemble of the robot arm is complete

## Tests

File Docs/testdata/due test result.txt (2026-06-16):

[10:34:37.543] [TX ] IK 150 0 150 0 3.14 0
[10:34:38.549] [RX ] Received IK event
[10:34:38.582] [RX ] -0.000081 -0.145631 2.236321 -0.002232 1.049270 0.000976
[10:34:38.582] [RX ] A motor move = -0.00
[10:34:38.586] [RX ] B motor move = -8.34
[10:34:38.586] [RX ] C motor move = 128.13
[10:34:38.590] [RX ] D motor move = -0.13
[10:34:38.590] [RX ] E motor move = 60.12
[10:34:38.593] [RX ] F motor move = 0.06
[10:35:13.951] [TX ] IK 150 0 200 0 3.14 0
[10:35:14.957] [RX ] Received IK event
[10:35:15.006] [RX ] -0.000110 -0.233804 2.051406 -0.001634 1.322403 0.000260
[10:35:15.006] [RX ] A motor move = -0.01
[10:35:15.006] [RX ] B motor move = -13.40
[10:35:15.007] [RX ] C motor move = 117.54
[10:35:15.007] [RX ] D motor move = -0.09
[10:35:15.007] [RX ] E motor move = 75.77
[10:35:15.007] [RX ] F motor move = 0.01
[10:35:19.655] [TX ] IK 150 0 150 0 3.14 0
[10:35:20.662] [RX ] Received IK event
[10:35:20.691] [RX ] -0.000081 -0.145631 2.236321 -0.002232 1.049270 0.000976
[10:35:20.695] [RX ] A motor move = -0.00
[10:35:20.695] [RX ] B motor move = -8.34
[10:35:20.699] [RX ] C motor move = 128.13
[10:35:20.699] [RX ] D motor move = -0.13
[10:35:20.703] [RX ] E motor move = 60.12
[10:35:20.703] [RX ] F motor move = 0.06
[10:35:24.231] [TX ] IK 150 0 200 0 3.14 0
[10:35:25.237] [RX ] Received IK event
[10:35:25.274] [RX ] -0.000110 -0.233804 2.051406 -0.001634 1.322403 0.000260
[10:35:25.275] [RX ] A motor move = -0.01
[10:35:25.275] [RX ] B motor move = -13.40
[10:35:25.278] [RX ] C motor move = 117.54
[10:35:25.279] [RX ] D motor move = -0.09
[10:35:25.282] [RX ] E motor move = 75.77
[10:35:25.283] [RX ] F motor move = 0.01
[10:35:28.807] [TX ] IK 150 0 150 0 3.14 0
[10:35:29.812] [RX ] Received IK event
[10:35:29.845] [RX ] -0.000081 -0.145631 2.236321 -0.002232 1.049270 0.000976
[10:35:29.846] [RX ] A motor move = -0.00
[10:35:29.849] [RX ] B motor move = -8.34
[10:35:29.850] [RX ] C motor move = 128.13
[10:35:29.853] [RX ] D motor move = -0.13
[10:35:29.854] [RX ] E motor move = 60.12
[10:35:29.857] [RX ] F motor move = 0.06
[10:35:34.039] [TX ] IK 150 0 200 0 3.14 0
[10:35:35.043] [RX ] Received IK event
[10:35:35.080] [RX ] -0.000110 -0.233804 2.051406 -0.001634 1.322403 0.000260
[10:35:35.084] [RX ] A motor move = -0.01
[10:35:35.084] [RX ] B motor move = -13.40
[10:35:35.088] [RX ] C motor move = 117.54
[10:35:35.088] [RX ] D motor move = -0.09
[10:35:35.093] [RX ] E motor move = 75.77
[10:35:35.093] [RX ] F motor move = 0.01
[10:35:36.399] [TX ] IK 150 0 150 0 3.14 0
[10:35:37.406] [RX ] Received IK event
[10:35:37.435] [RX ] -0.000081 -0.145631 2.236321 -0.002232 1.049270 0.000976
[10:35:37.439] [RX ] A motor move = -0.00
[10:35:37.439] [RX ] B motor move = -8.34
[10:35:37.443] [RX ] C motor move = 128.13
[10:35:37.443] [RX ] D motor move = -0.13
[10:35:37.447] [RX ] E motor move = 60.12
[10:35:37.447] [RX ] F motor move = 0.06
[10:35:40.631] [TX ] IK 150 0 200 0 3.14 0
[10:35:41.637] [RX ] Received IK event
[10:35:41.674] [RX ] -0.000110 -0.233804 2.051406 -0.001634 1.322403 0.000260
[10:35:41.674] [RX ] A motor move = -0.01
[10:35:41.678] [RX ] B motor move = -13.40
[10:35:41.678] [RX ] C motor move = 117.54
[10:35:41.679] [RX ] D motor move = -0.09
[10:35:41.682] [RX ] E motor move = 75.77
[10:35:41.682] [RX ] F motor move = 0.01

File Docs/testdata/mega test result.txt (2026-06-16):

[10:36:39.520] [TX ] IK 150 0 150 0 3.14 0
[10:36:40.526] [RX ] Received IK event
[10:36:40.788] [RX ] -0.000379 -0.145606 2.236302 -0.001838 1.049307 0.000538
[10:36:40.789] [RX ] A motor move = -0.02
[10:36:40.792] [RX ] B motor move = -8.34
[10:36:40.793] [RX ] C motor move = 128.13
[10:36:40.796] [RX ] D motor move = -0.11
[10:36:40.797] [RX ] E motor move = 60.12
[10:36:40.800] [RX ] F motor move = 0.03
[10:36:44.647] [TX ] IK 150 0 200 0 3.14 0
[10:36:45.655] [RX ] Received IK event
[10:36:45.950] [RX ] -0.000110 -0.233804 2.051406 -0.001634 1.322403 0.000260
[10:36:45.950] [RX ] A motor move = -0.01
[10:36:45.954] [RX ] B motor move = -13.40
[10:36:45.954] [RX ] C motor move = 117.54
[10:36:45.958] [RX ] D motor move = -0.09
[10:36:45.958] [RX ] E motor move = 75.77
[10:36:45.962] [RX ] F motor move = 0.01
[10:36:53.295] [TX ] IK 150 0 150 0 3.14 0
[10:36:54.302] [RX ] Received IK event
[10:36:54.565] [RX ] -0.000379 -0.145606 2.236302 -0.001838 1.049307 0.000538
[10:36:54.565] [RX ] A motor move = -0.02
[10:36:54.569] [RX ] B motor move = -8.34
[10:36:54.570] [RX ] C motor move = 128.13
[10:36:54.573] [RX ] D motor move = -0.11
[10:36:54.573] [RX ] E motor move = 60.12
[10:36:54.577] [RX ] F motor move = 0.03
[10:36:57.743] [TX ] IK 150 0 200 0 3.14 0
[10:36:58.751] [RX ] Received IK event
[10:36:59.046] [RX ] -0.000110 -0.233804 2.051406 -0.001634 1.322403 0.000260
[10:36:59.046] [RX ] A motor move = -0.01
[10:36:59.050] [RX ] B motor move = -13.40
[10:36:59.050] [RX ] C motor move = 117.54
[10:36:59.054] [RX ] D motor move = -0.09
[10:36:59.055] [RX ] E motor move = 75.77
[10:36:59.058] [RX ] F motor move = 0.01
[10:37:01.543] [TX ] IK 150 0 150 0 3.14 0
[10:37:02.549] [RX ] Received IK event
[10:37:02.811] [RX ] -0.000379 -0.145606 2.236302 -0.001838 1.049307 0.000538
[10:37:02.811] [RX ] A motor move = -0.02
[10:37:02.815] [RX ] B motor move = -8.34
[10:37:02.815] [RX ] C motor move = 128.13
[10:37:02.819] [RX ] D motor move = -0.11
[10:37:02.819] [RX ] E motor move = 60.12
[10:37:02.823] [RX ] F motor move = 0.03
[10:37:06.495] [TX ] IK 150 0 200 0 3.14 0
[10:37:07.501] [RX ] Received IK event
[10:37:07.796] [RX ] -0.000110 -0.233804 2.051406 -0.001634 1.322403 0.000260
[10:37:07.800] [RX ] A motor move = -0.01
[10:37:07.800] [RX ] B motor move = -13.40
[10:37:07.804] [RX ] C motor move = 117.54
[10:37:07.804] [RX ] D motor move = -0.09
[10:37:07.808] [RX ] E motor move = 75.77
[10:37:07.808] [RX ] F motor move = 0.01
[10:37:09.303] [TX ] IK 150 0 150 0 3.14 0
[10:37:10.311] [RX ] Received IK event
[10:37:10.569] [RX ] -0.000379 -0.145606 2.236302 -0.001838 1.049307 0.000538
[10:37:10.573] [RX ] A motor move = -0.02
[10:37:10.574] [RX ] B motor move = -8.34
[10:37:10.577] [RX ] C motor move = 128.13
[10:37:10.578] [RX ] D motor move = -0.11
[10:37:10.581] [RX ] E motor move = 60.12
[10:37:10.582] [RX ] F motor move = 0.03
[10:37:15.991] [TX ] IK 150 0 200 0 3.14 0
[10:37:16.997] [RX ] Received IK event
[10:37:17.296] [RX ] -0.000110 -0.233804 2.051406 -0.001634 1.322403 0.000260
[10:37:17.296] [RX ] A motor move = -0.01
[10:37:17.300] [RX ] B motor move = -13.40
[10:37:17.300] [RX ] C motor move = 117.54
[10:37:17.304] [RX ] D motor move = -0.09
[10:37:17.304] [RX ] E motor move = 75.77
[10:37:17.304] [RX ] F motor move = 0.01
[10:37:20.423] [TX ] IK 150 0 150 0 3.14 0
[10:37:21.429] [RX ] Received IK event
[10:37:21.691] [RX ] -0.000379 -0.145606 2.236302 -0.001838 1.049307 0.000538
[10:37:21.695] [RX ] A motor move = -0.02
[10:37:21.695] [RX ] B motor move = -8.34
[10:37:21.699] [RX ] C motor move = 128.13
[10:37:21.700] [RX ] D motor move = -0.11
[10:37:21.703] [RX ] E motor move = 60.12
[10:37:21.703] [RX ] F motor move = 0.03
[10:37:25.056] [TX ] IK 150 0 200 0 3.14 0
[10:37:26.062] [RX ] Received IK event
[10:37:26.357] [RX ] -0.000110 -0.233804 2.051406 -0.001634 1.322403 0.000260
[10:37:26.361] [RX ] A motor move = -0.01
[10:37:26.361] [RX ] B motor move = -13.40
[10:37:26.365] [RX ] C motor move = 117.54
[10:37:26.365] [RX ] D motor move = -0.09
[10:37:26.369] [RX ] E motor move = 75.77
[10:37:26.369] [RX ] F motor move = 0.01

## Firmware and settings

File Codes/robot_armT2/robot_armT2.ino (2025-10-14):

#include <Wire.h>
#include <Servo.h>
#include <AccelStepper.h>
#include <MultiStepper.h>
#include <math.h>

// =================================================================================
// <<< 新增的全域變數 >>>
// volatile 關鍵字是必須的，因為此變數會在中斷(receiveEvent)中被修改
volatile bool newDataFromI2C = false; 
// 用於儲存從 I2C 完整接收到的指令
String i2cCommand = "";
// =================================================================================


// Define stepper pins
#define ASTEP_PIN 48  // Step pin
#define ADIR_PIN 50   // Direction pin
#define AENABLE 52
#define BSTEP_PIN 44  // Step pin
#define BDIR_PIN 46   // Direction pin
#define CSTEP_PIN 40  // Step pin
#define CDIR_PIN 42   // Direction pin
#define DSTEP_PIN 2   // Step pin
#define DDIR_PIN 5    // Direction pin
#define ESTEP_PIN 3   // Step pin
#define EDIR_PIN 6
#define FSTEP_PIN 4
#define FDIR_PIN 7
#define ENABLE 8

#define Aendstop 43
#define Bendstop 41
#define Cendstop 39
#define Dendstop 37
#define Eendstop 35
#define emergbtn 53

const int SLAVE_ADDRESS = 1;
char incomingByte = 0;

String i2cC = "";

float alocation = 0;
float blocation = 0;
float clocation = 0;
float dlocation = 0;
float elocation = 0;
float flocation = 0;
float clawlocation = 0;

long positions[6];

String I2Creturn = "";

// bool I2Cin = 0; // <<< 這個舊旗標不再需要，由 newDataFromI2C 取代

const float agear = 1;
const float bgear = 50;
const float cgear = 27;
const float dgear = 20;
const float egear = 1;
const float fgear = 1;
const float steppower = 4.4;  // 1/(360/steps/rev)
const float radtoang = 57.295;


// Steps per revolution for the motor
const float speed = 50;
const float maxspeed = 75;

const float accel = 500;
const float stepsPerRevolution = 1600;
// Microstepping multiplier (1, 2, 4, 8, 16, or 32)

// AccelStepper instance in driver mode
AccelStepper stepperA(AccelStepper::DRIVER, ASTEP_PIN, ADIR_PIN);
AccelStepper stepperB(AccelStepper::DRIVER, BSTEP_PIN, BDIR_PIN);
AccelStepper stepperC(AccelStepper::DRIVER, CSTEP_PIN, CDIR_PIN);
AccelStepper stepperD(AccelStepper::DRIVER, DSTEP_PIN, DDIR_PIN);
AccelStepper stepperE(AccelStepper::DRIVER, ESTEP_PIN, EDIR_PIN);
AccelStepper stepperF(AccelStepper::DRIVER, FSTEP_PIN, FDIR_PIN);
MultiStepper robot2T;
Servo claw;

static const int DOF = 6;
static const float alpha_[DOF] = { -1.57f, 0.00f, 1.57f, -1.57f, 1.57f, 0.00f };     // radians
static const float a_[DOF] = { 0.000f, 252.625f, 0.000f, 0.000f, 0.000f, 0.000f };   // mm
static const float d_[DOF] = { 136.1f, 0.0f, 0.0f, 214.6f, 0.0f, 129.471f };         // mm
static const float theta_off_[DOF] = { 0.00f, -1.57f, 1.57f, 0.00f, 0.00f, 0.00f };  // radians

// IK settings
static const int MAX_ITERS = 120;     // iterations cap
static const float DAMPING = 0.02f;   // lambda for DLS (radians & mm units)void
static const float POS_TOL = 0.5f;    // mm
static const float ROT_TOL = 0.005f;  // rad (~0.29 deg)
// ---------------------------------------------------------------------------------
// Math helpers
// ---------------------------------------------------------------------------------
struct Vec3 {
  float x, y, z;
};

static inline float clampf(float x, float lo, float hi) {
  return x < lo ? lo : (x > hi ? hi : x);
}

static inline void mat4Mul(const float A[16], const float B[16], float C[16]) {
  for (int r = 0; r < 4; r++) {
    for (int c = 0; c < 4; c++) {
      float s = 0;
      for (int k = 0; k < 4; k++) s += A[r * 4 + k] * B[k * 4 + c];
      C[r * 4 + c] = s;
    }
  }
}

static inline void mat4Copy(const float S[16], float D[16]) {
  for (int i = 0; i < 16; i++) D[i] = S[i];
}

static inline void mat4FromDH(float a, float alpha, float d, float theta, float T[16]) {
  float ct = cosf(theta), st = sinf(theta);
  float ca = cosf(alpha), sa = sinf(alpha);
  T[0] = ct;
  T[1] = -st * ca;
  T[2] = st * sa;
  T[3] = a * ct;
  T[4] = st;
  T[5] = ct * ca;
  T[6] = -ct * sa;
  T[7] = a * st;
  T[8] = 0;
  T[9] = sa;
  T[10] = ca;
  T[11] = d;
  T[12] = 0;
  T[13] = 0;
  T[14] = 0;
  T[15] = 1;
}

static inline void mat4ExtractRPY_ZYX(const float T[16], float &rx, float &ry, float &rz) {
  // ZYX intrinsic (yaw Z, pitch Y, roll X). Using rotation matrix R = T[0..10].
  const float r00 = T[0], r01 = T[1], r02 = T[2];
  const float r10 = T[4], r11 = T[5], r12 = T[6];
  const float r20 = T[8], r21 = T[9], r22 = T[10];
  float pitch = asinf(-clampf(r20, -1.0f, 1.0f));
  float roll, yaw;
  if (fabsf(r20) < 0.9999f) {
    roll = atan2f(r21, r22);
    yaw = atan2f(r10, r00);
  } else {
    // Gimbal-close case: use alternative
    roll = 0.0f;
    yaw = atan2f(-r01, r11);
  }
  rx = roll;
  ry = pitch;
  rz = yaw;
}

static inline void rpyZYX_to_R(float rx, float ry, float rz, float R[9]) {
  // rx=roll(X), ry=pitch(Y), rz=yaw(Z)
  float cx = cosf(rx), sx = sinf(rx);
  float cy = cosf(ry), sy = sinf(ry);
  float cz = cosf(rz), sz = sinf(rz);
  // R = Rz(rz)*Ry(ry)*Rx(rx)
  R[0] = cz * cy;
  R[1] = cz * sy * sx - sz * cx;
  R[2] = cz * sy * cx + sz * sx;
  R[3] = sz * cy;
  R[4] = sz * sy * sx + cz * cx;
  R[5] = sz * sy * cx - cz * sx;
  R[6] = -sy;
  R[7] = cy * sx;
  R[8] = cy * cx;
}

static inline void R_to_axisAngle(const float R[9], float axis[3], float &angle) {
  float tr = R[0] + R[4] + R[8];
  float c = (tr - 1.0f) * 0.5f;
  c = clampf(c, -1.0f, 1.0f);
  angle = acosf(c);
  if (angle < 1e-6f) {
    axis[0] = axis[1] = axis[2] = 0;
    angle = 0;
    return;
  }
  float denom = 2.0f * sinf(angle);
  axis[0] = (R[7] - R[5]) / denom;
  axis[1] = (R[2] - R[6]) / denom;
  axis[2] = (R[3] - R[1]) / denom;
}

// ---------------------------------------------------------------------------------
// Forward Kinematics
// ---------------------------------------------------------------------------------
static void fk(const float q[DOF], float T[16]) {
  float Ti[16], Tacc[16];
  // Init to identity
  for (int i = 0; i < 16; i++) Tacc[i] = (i % 5 == 0) ? 1.0f : 0.0f;
  for (int i = 0; i < DOF; i++) {
    float theta = q[i] + theta_off_[i];
    mat4FromDH(a_[i], alpha_[i], d_[i], theta, Ti);
    float Tnew[16];
    mat4Mul(Tacc, Ti, Tnew);
    mat4Copy(Tnew, Tacc);
  }
  mat4Copy(Tacc, T);
}

// ---------------------------------------------------------------------------------
// Jacobian (geometric) for 6R arm
// ---------------------------------------------------------------------------------
static void jacobian(const float q[DOF], float J[6 * DOF]) {
  float Tacc[16];
  // identity
  for (int i = 0; i < 16; i++) Tacc[i] = (i % 5 == 0) ? 1.0f : 0.0f;

  float origins[DOF + 1][3];
  float zaxes[DOF + 1][3];

  // base frame
  origins[0][0] = 0;
  origins[0][1] = 0;
  origins[0][2] = 0;
  zaxes[0][0] = 0;
  zaxes[0][1] = 0;
  zaxes[0][2] = 1;

  // accumulate frames
  for (int i = 0; i < DOF; i++) {
    float Ti[16];
    float theta = q[i] + theta_off_[i];
    mat4FromDH(a_[i], alpha_[i], d_[i], theta, Ti);
    float Tnew[16];
    mat4Mul(Tacc, Ti, Tnew);
    mat4Copy(Tnew, Tacc);

    origins[i + 1][0] = Tacc[3];
    origins[i + 1][1] = Tacc[7];
    origins[i + 1][2] = Tacc[11];

    zaxes[i + 1][0] = Tacc[2];
    zaxes[i + 1][1] = Tacc[6];
    zaxes[i + 1][2] = Tacc[10];
  }

  float pe[3] = { origins[DOF][0], origins[DOF][1], origins[DOF][2] };

  for (int i = 0; i < DOF; i++) {
    float zi[3] = { zaxes[i][0], zaxes[i][1], zaxes[i][2] };
    float pi[3] = { origins[i][0], origins[i][1], origins[i][2] };
    float r[3] = { pe[0] - pi[0], pe[1] - pi[1], pe[2] - pi[2] };
    // cross(zi, r)
    float jv[3] = { zi[1] * r[2] - zi[2] * r[1], zi[2] * r[0] - zi[0] * r[2], zi[0] * r[1] - zi[1] * r[0] };

    J[0 * DOF + i] = jv[0];
    J[1 * DOF + i] = jv[1];
    J[2 * DOF + i] = jv[2];
    J[3 * DOF + i] = zi[0];
    J[4 * DOF + i] = zi[1];
    J[5 * DOF + i] = zi[2];
  }
}

// Multiply 6x6 with 6x1: y = A*x
static inline void mat6x6_mul_vec(const float A[36], const float x[6], float y[6]) {
  for (int r = 0; r < 6; r++) {
    float s = 0;
    for (int c = 0; c < 6; c++) s += A[r * 6 + c] * x[c];
    y[r] = s;
  }
}

// Build normal matrix A = J*J^T + (lambda^2) I (6x6) and compute its inverse via adjugate/Gauss-Jordan (simple, not super-optimized)
// Returns false if singular.
static bool invert6x6(const float A[36], float invA[36]) {
  // Augment [A | I] and perform Gauss-Jordan
  float M[6][12];
  for (int r = 0; r < 6; r++) {
    for (int c = 0; c < 6; c++) M[r][c] = A[r * 6 + c];
    for (int c = 0; c < 6; c++) M[r][6 + c] = (r == c) ? 1.0f : 0.0f;
  }
  for (int i = 0; i < 6; i++) {
    // pivot
    int piv = i;
    float maxA = fabsf(M[i][i]);
    for (int r = i + 1; r < 6; r++) {
      float v = fabsf(M[r][i]);
      if (v > maxA) {
        maxA = v;
        piv = r;
      }
    }
    if (maxA < 1e-8f) return false;
    if (piv != i) {
      for (int c = 0; c < 12; c++) {
        float tmp = M[i][c];
        M[i][c] = M[piv][c];
        M[piv][c] = tmp;
      }
    }
    // normalize row
    float diag = M[i][i];
    for (int c = 0; c < 12; c++) M[i][c] /= diag;
    // eliminate
    for (int r = 0; r < 6; r++)
      if (r != i) {
        float f = M[r][i];
        if (f != 0) {
          for (int c = 0; c < 12; c++) M[r][c] -= f * M[i][c];
        }
      }
  }
  // extract inv
  for (int r = 0; r < 6; r++)
    for (int c = 0; c < 6; c++) invA[r * 6 + c] = M[r][6 + c];
  return true;
}

// Compute error twist between current T(q) and desired pose (x,y,z, rpy_ZYX)
static void poseError(const float Tcurr[16], const float p_des[3], const float rpy_des[3], float e[6]) {
  // position error
  e[0] = p_des[0] - Tcurr[3];
  e[1] = p_des[1] - Tcurr[7];
  e[2] = p_des[2] - Tcurr[11];
  // orientation error via axis-angle of R_err = R_des * R_curr^T
  float Rcurr[9] = { Tcurr[0], Tcurr[1], Tcurr[2], Tcurr[4], Tcurr[5], Tcurr[6], Tcurr[8], Tcurr[9], Tcurr[10] };
  float Rdes[9];
  rpyZYX_to_R(rpy_des[0], rpy_des[1], rpy_des[2], Rdes);
  // R_err = Rdes * Rcurr^T
  float Rct[9] = { Rcurr[0], Rcurr[3], Rcurr[6], Rcurr[1], Rcurr[4], Rcurr[7], Rcurr[2], Rcurr[5], Rcurr[8] };
  float Rerr[9];
  for (int r = 0; r < 3; r++)
    for (int c = 0; c < 3; c++) {
      float s = 0;
      for (int k = 0; k < 3; k++) s += Rdes[r * 3 + k] * Rct[k * 3 + c];
      Rerr[r * 3 + c] = s;
    }
  float axis[3];
  float ang;
  R_to_axisAngle(Rerr, axis, ang);
  e[3] = axis[0] * ang;
  e[4] = axis[1] * ang;
  e[5] = axis[2] * ang;  // small-angle rotation vector
}

// Damped Least Squares IK: returns true if converged, q is updated in-place
static bool ik_solve(float q[DOF], const float p_des[3], const float rpy_des[3]) {
  for (int iter = 0; iter < MAX_ITERS; ++iter) {
    // FK and error
    float Tcurr[16];
    fk(q, Tcurr);
    float e[6];
    poseError(Tcurr, p_des, rpy_des, e);

    float pos_err = sqrtf(e[0] * e[0] + e[1] * e[1] + e[2] * e[2]);
    float rot_err = sqrtf(e[3] * e[3] + e[4] * e[4] + e[5] * e[5]);
    if (pos_err < POS_TOL && rot_err < ROT_TOL) return true;

    // Jacobian
    float J[6 * DOF];
    jacobian(q, J);

    // A = J*J^T + λ^2 I (6x6)
    float A[36] = { 0 };
    for (int r = 0; r < 6; r++) {
      for (int c = 0; c < 6; c++) {
        float s = 0;
        for (int k = 0; k < DOF; k++) s += J[r * DOF + k] * J[c * DOF + k];
        A[r * 6 + c] = s;
      }
      A[r * 6 + r] += (DAMPING * DAMPING);
    }
    float invA[36];
    if (!invert6x6(A, invA)) return false;

    // y = invA * e
    float y[6];
    mat6x6_mul_vec(invA, e, y);

    // dq = J^T * y
    float dq[DOF];
    for (int i = 0; i < DOF; i++) {
      float s = 0;
      for (int r = 0; r < 6; r++) s += J[r * DOF + i] * y[r];
      dq[i] = s;
    }

    // step size limiting (simple clipping)
    const float MAX_STEP = 0.2f;  // rad per iter (or mm-equivalent via Jacobian mapping)
    for (int i = 0; i < DOF; i++) dq[i] = clampf(dq[i], -MAX_STEP, MAX_STEP);

    for (int i = 0; i < DOF; i++) q[i] += dq[i];
  }
  return false;  // not converged
}

// ---------------------------------------------------------------------------------
// Serial parsing helpers
// ---------------------------------------------------------------------------------
static bool readLine(String &out) {
  if (!Serial.available()) return false;
  out = Serial.readStringUntil('\n');
  out.trim();
  return out.length() > 0;
}

static int splitTokens(const String &s, String tokens[], int maxTok) {
  int n = 0;
  int i = 0;
  while (i < s.length() && n < maxTok) {
    while (i < s.length() && isspace(s[i])) i++;
    if (i >= s.length()) break;
    int j = i;
    while (j < s.length() && !isspace(s[j])) j++;
    tokens[n++] = s.substring(i, j);
    i = j;
  }
  return n;
}

static bool parseFloats(String tokens[], int start, int count, float *out) {
  for (int i = 0; i < count; i++) {
    char *endptr;
    String t = tokens[start + i];
    out[i] = t.toFloat();  // Arduino String has toFloat()
  }
  return true;
}

static void printArray(const float *v, int n) {
  for (int i = 0; i < n; i++) {
    if (i) Serial.print(' ');
    // print with 6 decimals
    Serial.print(v[i], 6);
  }
  Serial.println();
}
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
void loop() {
  if (digitalRead(emergbtn) == HIGH) {
    motorzero();
  }

  // =================================================================================
  // <<< 主要修改部分 >>>
  // 檢查是否有新的 I2C 指令需要處理
  if (newDataFromI2C) {
    // 立刻重置旗標，這樣可以準備接收下一筆指令
    // 把這行放在最前面，可以避免在處理期間錯過新的指令
    newDataFromI2C = false;

    Serial.println("Received I2C command, now processing...");
    
    // 呼叫一個獨立的函式來處理指令，讓 loop() 保持乾淨
    handleI2CCommand(); 
  }
  // =================================================================================


  robot2T.run();

  String line;
  if (!readLine(line)) return;  // no blocking
  String tok[20];
  int n = splitTokens(line, tok, 20);
  if (n <= 0) return;

  if (tok[0] == "FK" && n == 1 + DOF) {
    float q[DOF];
    parseFloats(tok, 1, DOF, q);
    float T[16];
    fk(q, T);
    float rx, ry, rz;
    mat4ExtractRPY_ZYX(T, rx, ry, rz);
    float out[6] = { T[3], T[7], T[11], rx, ry, rz };
    printArray(out, 6);
  } else if (tok[0] == "IK" && (n == 1 + 6 || n == 1 + 6 + DOF)) {
    float p[3], rpy[3];
    parseFloats(tok, 1, 3, p);
    parseFloats(tok, 4, 3, rpy);
    float q[DOF] = { 0, 0, 1.57, 0, 0, 0 };
    if (n == 1 + 6 + DOF) parseFloats(tok, 1 + 6, DOF, q);

    bool ok = ik_solve(q, p, rpy);
    if (!ok) Serial.print(F("#WARN: not fully converged -> "));
    printArray(q, DOF);
    motormove(q);
  } else if (tok[0] == "HELP") {
    Serial.println(F("FK q1 q2 q3 q4 q5 q6"));
    Serial.println(F("IK X Y Z RX RY RZ [q1 q2 q3 q4 q5 q6]"));
  } else if (tok[0] == "jm") {
    alocation = tok[1].toFloat();
    blocation = tok[2].toFloat();
    clocation = tok[3].toFloat();
    dlocation = tok[4].toFloat();
    elocation = tok[5].toFloat();
    flocation = tok[6].toFloat();
    if (alocation <= 90 && alocation >= -90) {
      Serial.print("A motor move = ");
      Serial.println(alocation);
      positions[0] = alocation * agear * steppower;
      //stepperA.moveTo(alocation * agear * steppower);
    }
    if (blocation <= 90 && blocation >= -90) {
      Serial.print("B motor move = ");
      Serial.println(blocation);
      positions[1] = blocation * bgear * steppower;
      //stepperB.moveTo(blocation * bgear * steppower);
    }
    if (clocation <= 160 && clocation >= -160) {
      Serial.print("C motor move = ");
      Serial.println(clocation);
      positions[2] = -1 * (clocation - 5) * cgear * steppower;
      //stepperC.moveTo(-1 * (clocation - 5) * cgear * steppower);
    }
    if (dlocation <= 170 && dlocation >= -170) {
      Serial.print("D motor move = ");
      Serial.println(dlocation);
      positions[3] = -1 * (dlocation - 3) * dgear * steppower;
      //stepperD.moveTo(-1 * (dlocation - 3) * dgear * steppower);
    }
    if (elocation <= 90 && elocation >= -90) {
      Serial.print("E motor move = ");
      Serial.println(elocation);
      positions[4] = elocation * egear * steppower;
      //stepperE.moveTo(elocation * egear * steppower);
    }
    if (flocation <= 180 && flocation >= -180) {
      Serial.print("F motor move = ");
      Serial.println(flocation);
      positions[5] = -1 * flocation * fgear * steppower;
      //stepperF.moveTo(-1 * flocation * fgear * steppower);
    }
    robot2T.moveTo(positions);
  } else if (tok[0] == "zro") {
    motorzero();
  } else if (tok[0] == "clm") {
    clawlocation = tok[1].toFloat();
    if (clawlocation <= 180 && clawlocation >= 0) {
      Serial.print("claw motor move = ");
      Serial.println(clawlocation);
      claw.write(clawlocation);
    }
  } else {
    Serial.println(F("#ERR: bad command. Use HELP"));
  }
}


// =================================================================================
// <<< 修改後的 receiveEvent 函式 >>>
// 這個函式現在非常輕量，只負責接收字串並設定旗標，執行速度極快。
// =================================================================================
void receiveEvent(int howMany) {
  i2cCommand = ""; // 清空舊指令
  while (Wire.available() > 0)
  {
    char c = Wire.read();
    i2cCommand += c; // 將收到的字元存到全域變數中
  }
  newDataFromI2C = true; // 設定旗標，通知 loop() 有新指令
}

// =================================================================================
// <<< 新增的 I2C 指令處理函式 >>>
// 這裡面是您原本放在 receiveEvent 裡的完整處理邏輯。
// 現在它在主程式 loop() 中被安全地呼叫，不會再造成中斷問題。
// =================================================================================
void handleI2CCommand() {
  Serial.print("Full command received: ");
  Serial.println(i2cCommand); // 在這裡印出收到的完整指令

  String tok[20];
  int n = splitTokens(i2cCommand, tok, 20);
  if (n <= 0) return;

  if (tok[0] == "IK" && (n == 1 + 6)) {
    float p[3], rpy[3];
    parseFloats(tok, 1, 3, p);
    parseFloats(tok, 4, 3, rpy);
    float q[DOF] = { 0, 0, 1.57, 0, 0, 0 };
    // This part of your original code was unreachable, but I've kept it for consistency
    if (n == 1 + 6 + DOF) parseFloats(tok, 1 + 6, DOF, q); 

    bool ok = ik_solve(q, p, rpy);
    if (!ok) Serial.print(F("#WARN: not fully converged -> "));
    
    Serial.print("IK result (raw): ");
    printArray(q, DOF);
    
    // Your original rounding logic
    float qs[6];
    for (int i = 0; i < 6; i++) { // Corrected loop to process all 6 DOFs
      qs[i] = round(q[i] * 100.0) / 100.0;
    }
    Serial.print("IK result (rounded): ");
    printArray(qs, DOF);

    // Call motormove with the original high-precision values
    motormove(q);
  } 
  // You can add your other I2C commands (like "zro", "clm") here if needed
  else if (tok[0] == "zro") {
      motorzero();
  } else if (tok[0] == "clm") {
      clawlocation = tok[1].toFloat();
      if (clawlocation <= 180 && clawlocation >= 0) {
        Serial.print("claw motor move = ");
        Serial.println(clawlocation);
        claw.write(clawlocation);
      }
  } else {
      Serial.println("#ERR: Unknown I2C command or wrong parameters.");
  }
}


void motorzero() {
  stepperA.setSpeed(speed * agear);
  stepperA.setAcceleration(accel * agear);
  stepperB.setSpeed(speed * bgear);
  stepperB.setAcceleration(accel * bgear);
  stepperC.setSpeed(speed * cgear);
  stepperC.setAcceleration(accel * cgear);
  stepperD.setSpeed(speed * dgear);
  stepperD.setAcceleration(accel * dgear);
  stepperE.setSpeed(speed * egear);
  stepperE.setAcceleration(accel * egear);
  stepperF.setSpeed(speed * fgear);
  stepperF.setAcceleration(accel * fgear);
  stepperF.runToNewPosition(180 * fgear * steppower);
  stepperF.runToNewPosition(-180 * fgear * steppower);
  stepperF.runToNewPosition(0 * fgear * steppower);
  stepperE.setSpeed(-100);  //j5
  while (digitalRead(Eendstop) == LOW) {
    stepperE.runSpeed();
  }
  stepperE.setCurrentPosition(0);
  delay(200);

  stepperE.runToNewPosition(50);
  stepperE.setSpeed(-25);
  while (digitalRead(Eendstop) == LOW) {
    stepperE.runSpeed();
  }
  stepperE.setCurrentPosition(0);
  stepperE.runToNewPosition(-35);
  stepperE.setCurrentPosition(0);  //j5 zero finish

  stepperA.setSpeed(-100);  //j1
  while (digitalRead(Aendstop) == LOW) {
    stepperA.runSpeed();
  }
  stepperA.setCurrentPosition(0);
  delay(200);

  stepperA.runToNewPosition(50);
  stepperA.setSpeed(-25);
  while (digitalRead(Aendstop) == LOW) {
    stepperA.runSpeed();
  }
  stepperA.setCurrentPosition(0);  //j1 zero finish

  //stepperC.runToNewPosition(30 * cgear * steppower);  //j3 make space for j2

  stepperB.setSpeed(-100 * bgear);  //j2
  while (digitalRead(Bendstop) == LOW) {
    stepperB.runSpeed();
  }
  stepperB.setCurrentPosition(0);
  delay(200);

  stepperB.runToNewPosition(50 * bgear);
  stepperB.setSpeed(-25 * bgear);
  while (digitalRead(Bendstop) == LOW) {
    stepperB.runSpeed();
  }
  stepperB.setCurrentPosition(0);
  stepperB.runToNewPosition(-250);
  stepperB.setCurrentPosition(0);  //j2 zero finish
  delay(200);
  stepperB.runToNewPosition(90 * bgear * steppower);  //j2 make space
  stepperB.setCurrentPosition(0);

  stepperD.setSpeed(-100 * dgear);  //j4
  while (digitalRead(Dendstop) == LOW) {
    stepperD.runSpeed();
  }
  stepperD.setCurrentPosition(0);
  delay(200);

  stepperD.runToNewPosition(50 * dgear);
  stepperD.setSpeed(-25 * dgear);
  while (digitalRead(Dendstop) == LOW) {
    stepperD.runSpeed();
  }
  stepperD.setCurrentPosition(0);
  stepperD.runToNewPosition(-250);
  stepperD.setCurrentPosition(0);
  delay(200);  //j4 zero finish
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

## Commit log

2026-01-18 3dfile update
    [ArduinoMega2560.SLDPRT, ArduinoMega2560.ipt, DM542.STEP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]
2026-05-17 assemble manual
    [BOM.xlsx]
